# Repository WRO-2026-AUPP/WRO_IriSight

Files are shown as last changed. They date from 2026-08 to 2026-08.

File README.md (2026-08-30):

# IriSight — WRO Future Engineers 2026

_Repository of Team IriSight competing in the CRO 2026, Future Engineers category._

<div align="center">
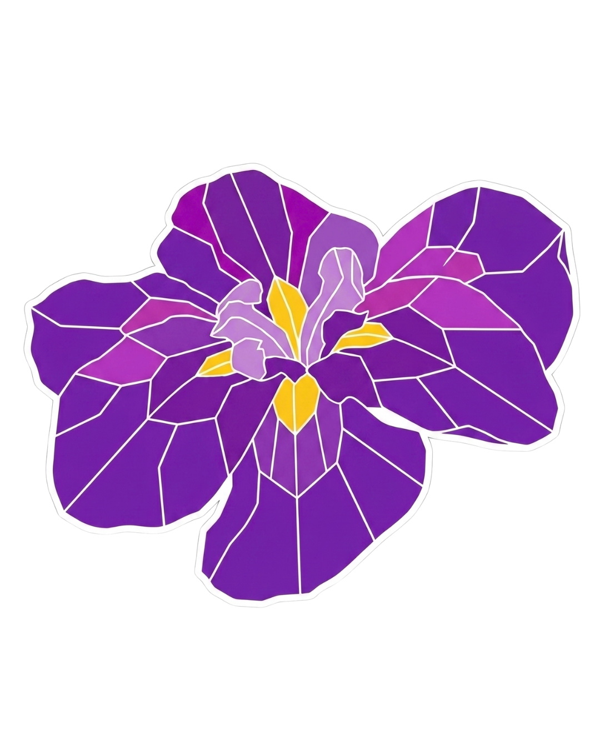
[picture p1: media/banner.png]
IriSight project banner
  
  <p><em>"Break, Fix, Repeat"</em></p>
</div>

## Quick Link - Explore the project

<table width="100%">
  <tr>
    <td width="33.33%" align="center" valign="top">
      <a href="src/"><strong>💻 Code</strong></a><br>
      <sub>Jetson and ESP32 control code</sub>
    </td>
    <td width="33.33%" align="center" valign="top">
      <a href="schemes/"><strong>🔌 Schematics</strong></a><br>
      <sub>Wiring, power, and electronics</sub>
    </td>
    <td width="33.33%" align="center" valign="top">
      <a href="models/"><strong>🧩 CAD models &amp; Mechanics</strong></a><br>
      <sub>Mechanical design and printable files</sub>
    </td>
  </tr>
  <tr>
    <td width="33.33%" align="center" valign="top">
      <a href="v-photos/"><strong>🚗 Vehicle Photos</strong></a><br>
      <sub>Required views of the final robot</sub>
    </td>
    <td width="33.33%" align="center" valign="top">
      <a href="t-photos/"><strong>👥 Team Photos</strong></a><br>
      <sub>Official and informal team photos</sub>
    </td>
    <td width="33.33%" align="center" valign="top">
      <a href="video/video.md"><strong>🎥 Videos</strong></a><br>
      <sub>Autonomous challenge demonstrations</sub>
    </td>
  </tr>
</table>

## Contents

- [Repository Structure](#repository-structure)
- [Meet the team](#meet-the-team)
- [Meet the vehicle](#meet-the-vehicle)
  - [Final vehicle gallery](#final-vehicle-gallery)
  - [Key specifications](#key-specifications)
- [Performance videos](#performance-videos)
- [How IriSight works](#how-irisight-works)
  - [System architecture](#system-architecture)
- [Our engineering journey](#our-engineering-journey)
  - [Final engineering blueprints](#final-engineering-blueprints)
- [Mobility and mechanical design](#mobility-and-mechanical-design)
  - [Chassis and component mounting](#chassis-and-component-mounting)
  - [Rear drive system](#rear-drive-system)
  - [Parallel steering](#parallel-steering)
  - [Mechanical iterations](#mechanical-iterations)
- [Power and sensor architecture](#power-and-sensor-architecture)
  - [Power architecture](#power-architecture)
  - [Component and interface map](#component-and-interface-map)
    - [Jetson](#jetson)
    - [Custom ESP32 Board](#custom-esp32-board)
    - [Motor Driver](#motor-driver)
    - [Steering Servo](#steering-servo)
    - [D455](#d455)
    - [IMU](#imu)
    - [Left/Right Ultrasonic](#leftright-ultrasonic)
    - [Jetson Battery](#jetson-battery)
    - [Motor Battery](#motor-battery)
    - [Buck-Boost Converter at 11V](#buck-boost-converter-at-11v)
    - [Buck Converter at 5V](#buck-converter-at-5v)
  - [Sensor placement and calibration](#sensor-placement-and-calibration)
- [Software and challenge strategy](#software-and-challenge-strategy)
  - [Architecture and communication](#architecture-and-communication)
  - [Open Challenge](#open-challenge)
    - [Current Control Value](#current-control-value)
    - [Test Results](#test-results)
  - [AI Model and Computer Vision Pipeline](#ai-model-and-computer-vision-pipeline)
    - [Detection Model](#detection-model)
    - [Dataset and Training Workflow](#dataset-and-training-workflow)
    - [How the Model Output Is Used in Control](#how-the-model-output-is-used-in-control)
  - [Obstacle Challenge](#obstacle-challenge)
    - [Current Control Values](#current-control-values)
    - [Test Results](#test-results-1)
- [System integration, testing, and risk](#system-integration-testing-and-risk)
  - [Subsystem interaction](#subsystem-interaction)
  - [Final regression results](#final-regression-results)
  - [Key decisions](#key-decisions)
  - [Risk register](#risk-register)
- [Reproducing IriSight](#reproducing-irisight)
  - [Required files and tools](#required-files-and-tools)
  - [Mechanical assembly](#mechanical-assembly)
  - [Wiring and power-on](#wiring-and-power-on)
  - [Software Installation](#software-installation)
  - [Calibration](#calibration)
  - [Start an Autonomous Run](#start-an-autonomous-run)
  - [Pre-flight and acceptance test](#pre-flight-and-acceptance-test)
- [Current limitations and next improvements](#current-limitations-and-next-improvements)
- [MIT License](#mit-license)

## Repository Structure

This repository is organized as follows:

```
📦 WRO_IriSight
├── 📁 media                    # Project banner and progress photos
│
├── 📁 models                   # 3D design files for the robot's printed components
│   ├── 📁 STEP_file             # Editable CAD source files
│   ├── 📁 STL_file              # Print-ready mesh files
│   └── 📁 png                   # Renders and engineering blueprints
│
├── 📁 schemes                  # Schematics and electrical documentation
│   ├── 📄 WRO_electrical_diagram.drawio  # Editable wiring/power diagram source
│   └── 📁 photos                # Photos and exported diagrams
│
├── 📁 src                      # Main source code for the robot
│   ├── 📁 ai_model              # YOLOv8n weights and object-detection docs
│   ├── 📁 helper_function       # BNO055 IMU driver, calibration data, ultrasonic firmware
│   ├── 📁 obs_challenge         # Obstacle Challenge control programs (CW/CCW)
│   └── 📁 open_challenge        # Open Challenge control programs (CW/CCW)
│
├── 📁 t-photos                 # Official and informal team photos
│
├── 📁 v-photos                 # Vehicle photo/video documentation
│   └── 📁 robot_photo           # Required six-side photos + 360° GIF
│
├── 📁 video                    # Link(s) to challenge demonstration videos
│
├── 📄 LICENSE.txt              # MIT License
└── 📄 README.md                # Main documentation for the project
```

## Meet the team

<div align="center">
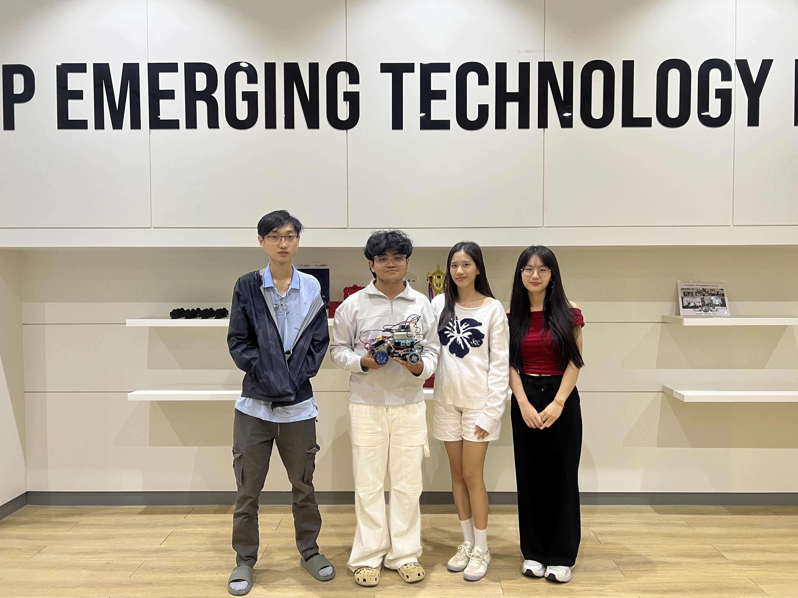
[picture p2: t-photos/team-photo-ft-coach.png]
Meet the team
  
  <p><em>Team Photo - From left to right: Kimchour, Panha (Coach), Nita, and Muyleang.</em></p>
</div>

<table style="border: 1px solid #ccc; width: 100%; border-collapse: collapse; margin-bottom: 20px;">
  <tr>
    <td width="30%" align="center" valign="top" style="padding: 15px; border-right: 1px solid #ccc;">
      <strong>Ponlork Ponita</strong><br><br>
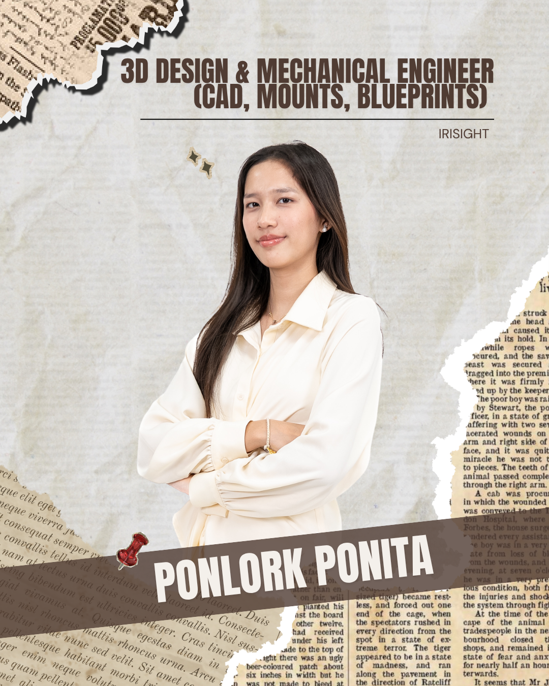
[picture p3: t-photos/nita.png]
Team member 1
      
    </td>
    <td width="70%" valign="top" style="padding: 15px;">
      <strong>Role:</strong> 3D Design & Mechanical Engineer (CAD, Mounts, Blueprints)<br><br>
      <strong>Origin:</strong> Phnom Penh<br><br>
      <strong>Email:</strong> 2024352ponlork@aupp.edu.kh<br><br>
      <strong>Bio:</strong> A junior student at the American University of Phnom Penh (AUPP), she led the CAD design of the team's 3D-printed structural parts. Including the Jetson & Battery Container, the rear Motor Mount, and the RealSense Camera Mount. She carried each component through multiple print-and-test-fit iterations to achieve a LEGO-compatible, chassis-mounted final version, meticulously documenting dimensions and material properties in her blueprint sheets.
    </td>
  </tr>
</table>

<table style="border: 1px solid #ccc; width: 100%; border-collapse: collapse; margin-bottom: 20px;">
  <tr>
    <td width="70%" valign="top" style="padding: 15px; border-right: 1px solid #ccc;">
      <strong>Role:</strong> Electrical & Sensor Engineer (Wiring, Power, Sensors)<br><br>
      <strong>Origin:</strong> Phnom Penh<br><br>
      <strong>Email:</strong> 2024355taing@aupp.edu.kh<br><br>
      <strong>Bio:</strong> Serving as the hardware integration lead, she managed the vehicle's electrical infrastructure. She mapped the custom wiring schematics, engineered a stable power distribution system for the compute and motor payloads, and rigorously tested and calibrated sensor placements to guarantee accurate real-time data collection for the system's navigation stack.
    </td>
    <td width="30%" align="center" valign="top" style="padding: 15px;">
      <strong>Taing Muyleang</strong><br><br>
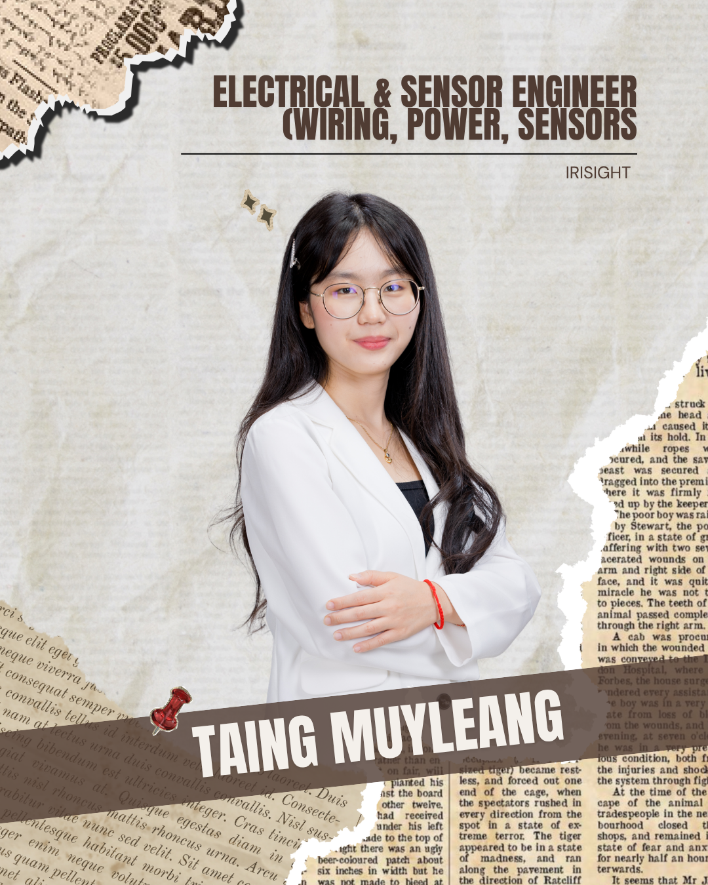
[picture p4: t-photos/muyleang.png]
Team member 2
      
    </td>
  </tr>
</table>

<table style="border: 1px solid #ccc; width: 100%; border-collapse: collapse; margin-bottom: 20px;">
  <tr>
    <td width="30%" align="center" valign="top" style="padding: 15px; border-right: 1px solid #ccc;">
      <strong>Luy Kimchour</strong><br><br>
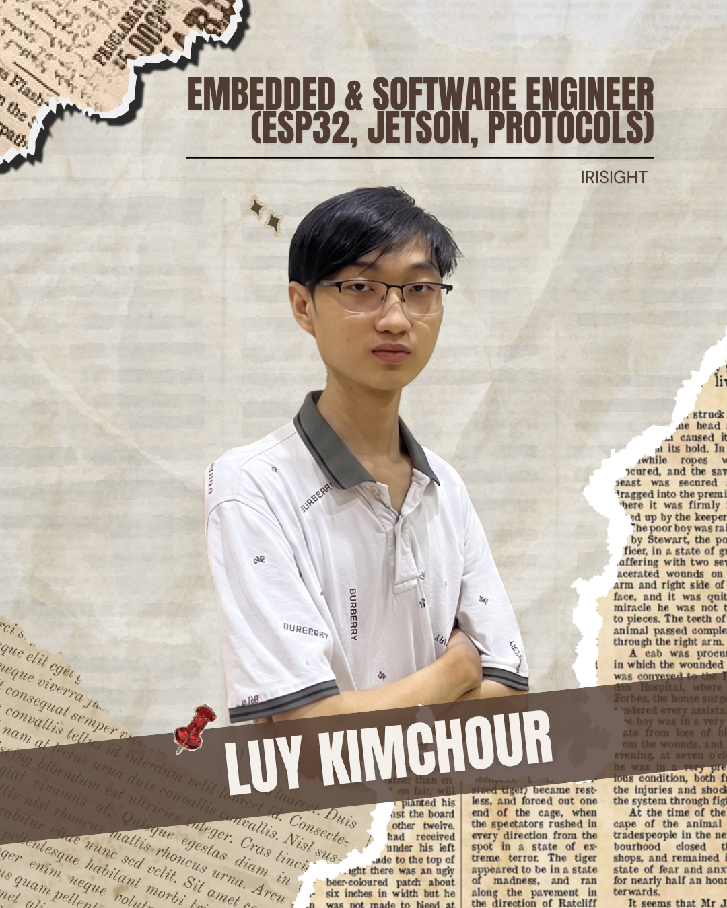
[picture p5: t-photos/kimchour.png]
Team member 3
      
    </td>
    <td width="70%" valign="top" style="padding: 15px;">
      <strong>Role:</strong> Embedded & Software Engineer (ESP32, Jetson, Protocols)<br><br>
      <strong>Origin:</strong> Phnom Penh<br><br>
      <strong>Email:</strong> 2025136luy@aupp.edu.kh<br><br>
      <strong>Bio:</strong> As the team's software lead, he developed the core system architecture, writing the ESP32 firmware and the Jetson control software. Backed by an extensive commit history in the project repository, his work focused on designing robust communication protocols to bridge the microcontrollers and compute modules, ensuring seamless data flow and reliable system execution.
    </td>
  </tr>
</table>

<table style="border: 1px solid #ccc; width: 100%; border-collapse: collapse; margin-bottom: 20px;">
  <tr>
    <td width="70%" valign="top" style="padding: 15px; border-right: 1px solid #ccc;">
      <strong>Role:</strong> Team Coach<br><br>
      <strong>Origin:</strong> Battambang<br><br>
      <strong>Email:</strong> 2024033chamroeun@aupp.edu.kh<br><br>
      <strong>Bio:</strong> A senior student majored in Information and Communication Technology at the American University of Phnom Penh, with experience in 3D modeling, CAD, vehicle design, and autonomous-vehicle software. In the previous season, he helped design and optimize the robot's custom parts and mechanical structure while also contributing to software, planning, coordination, and technical documentation. As IriSight's coach for the 2026 season, he uses that hands-on competition experience to guide the team through mechanical design, software development, system integration, testing, and documentation while keeping the engineering work student-led.
    </td>
    <td width="30%" align="center" valign="top" style="padding: 15px;">
      <strong>Chamroeun Vireakpanha</strong><br><br>
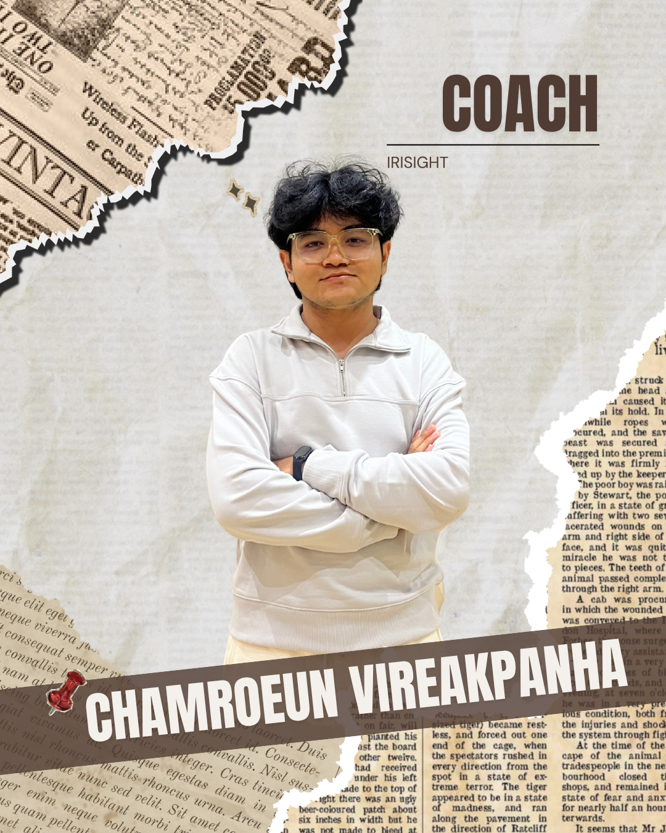
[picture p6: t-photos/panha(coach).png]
Team coach
      
    </td>
  </tr>
</table>

## Meet the vehicle
<div>
  Meet the vehicle
  <p><em>Vehicle 360º view (GIF)</em></p>
</div>

### Final vehicle gallery
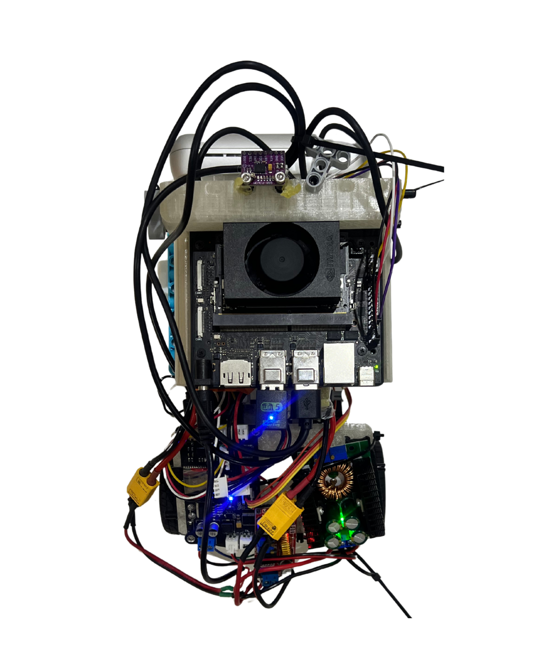
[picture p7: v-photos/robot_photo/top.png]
Top photo
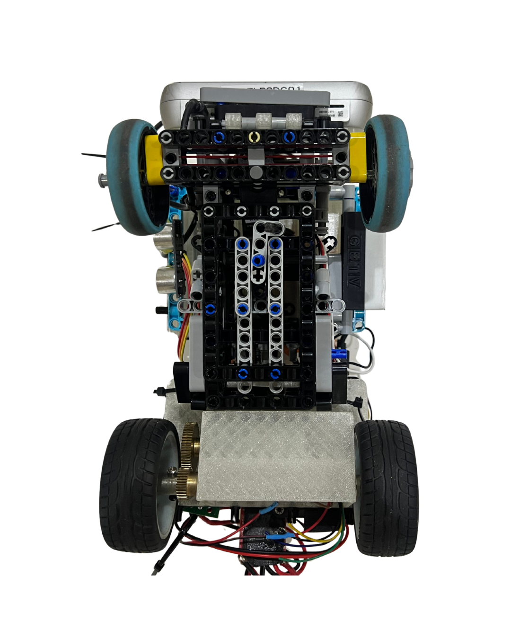
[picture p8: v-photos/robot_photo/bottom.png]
Bottom photo
|  |  |
| :---: | :---: |
| **Top** | **Bottom** |

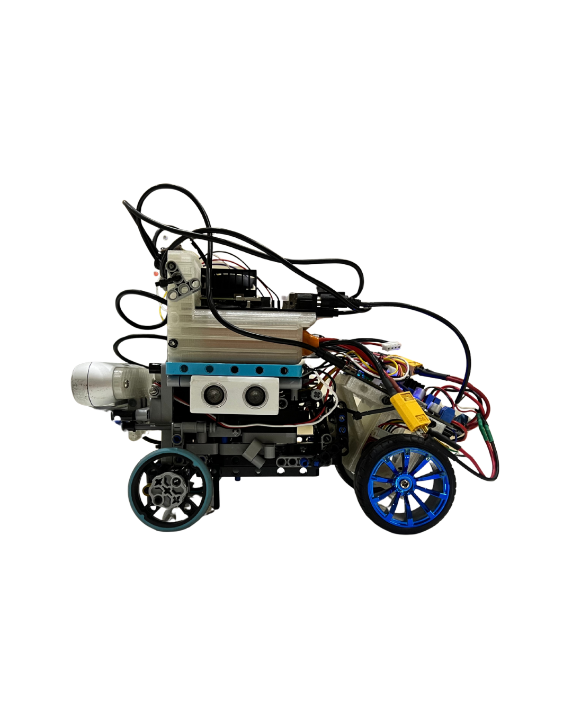
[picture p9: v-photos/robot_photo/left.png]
Left photo
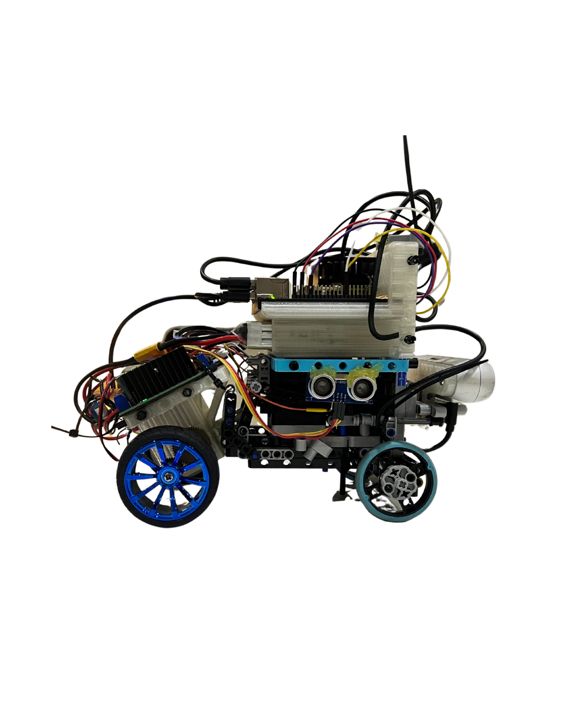
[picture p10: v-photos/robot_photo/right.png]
Right photo
|  |  |
| :---: | :---: |
| **Left** | **Right** |

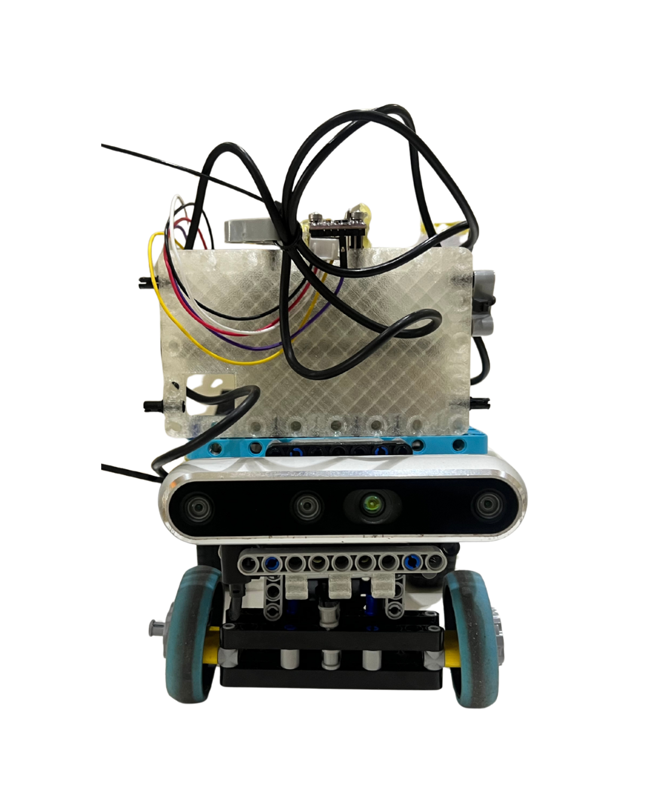
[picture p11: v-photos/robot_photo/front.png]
Front photo
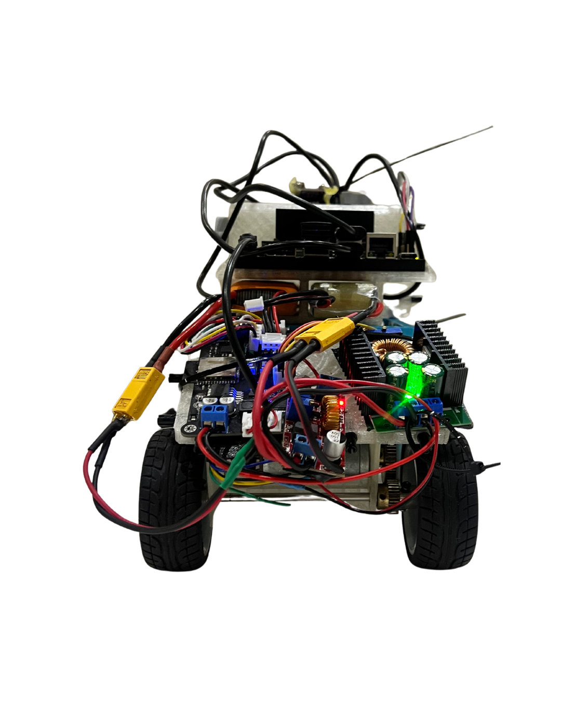
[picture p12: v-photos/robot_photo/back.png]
Back photo
|  |  |
| :---: | :---: |
| **Front** | **Back** |
### Key specifications

| Specification | Final value |
| --- | --- |
| Length × width × height | 26.3 x 15.2 x 21.2 (cm) |
| Mass | 1.38 KG |
| Wheelbase / track width | 15.3 cm |
| Ground clearance | 2.8 cm |
| Drive layout | One motor, two gears, one drive shaft, two driven back wheels |
| Steering layout | LEGO-based parallel front steering system|
| Main computer | NVIDIA Jetson Orin Nano, Ubuntu 22.04 LTS |
| Microcontroller | ESP32 |
| Primary camera | Intel RealSense D455 |
| IMU | BNO055 breakout |
| Additional sensors | Two side ultrasonic sensors |
| Chassis Type | Custom chassis |
| Front wheels | LEGO SPIKE blue wheels, part `39367` |
| Back wheels | RC Car Tires Wheels |
| Batteries | Separate Jetson and motor/actuator batteries |

## Performance videos

| Challenge | Video | 
| --- | --- |
| Open Challenge | [Watch on Youtube](https://youtu.be/7jsuhlpw6mA) | 
| Obstacle Challenge | [Watch on Youtube](https://youtu.be/TGH4JoCRx5o) | 

## How IriSight works

IriSight is a self-driving LEGO/3D-printed chassis robot built for WRO Future Engineers 2026. An NVIDIA Jetson Orin Nano runs the main perception and decision loop, reading depth/color from an Intel RealSense D455 and heading from a BNO055 IMU over I2C (plus two HC-SR04 ultrasonics wired to the ESP32 for close-range backup). The Jetson computes a steering angle and speed command and sends it over USB (power + serial) to an ESP32, which drives the rear motor through a TB6612FNG driver and turns the front wheels via a parallel-linkage steering servo. A Flask web stream exposes live diagnostics (mode, depth ROIs, steering, yaw, lap count) for tuning and debugging.

### System architecture

<div align="center">
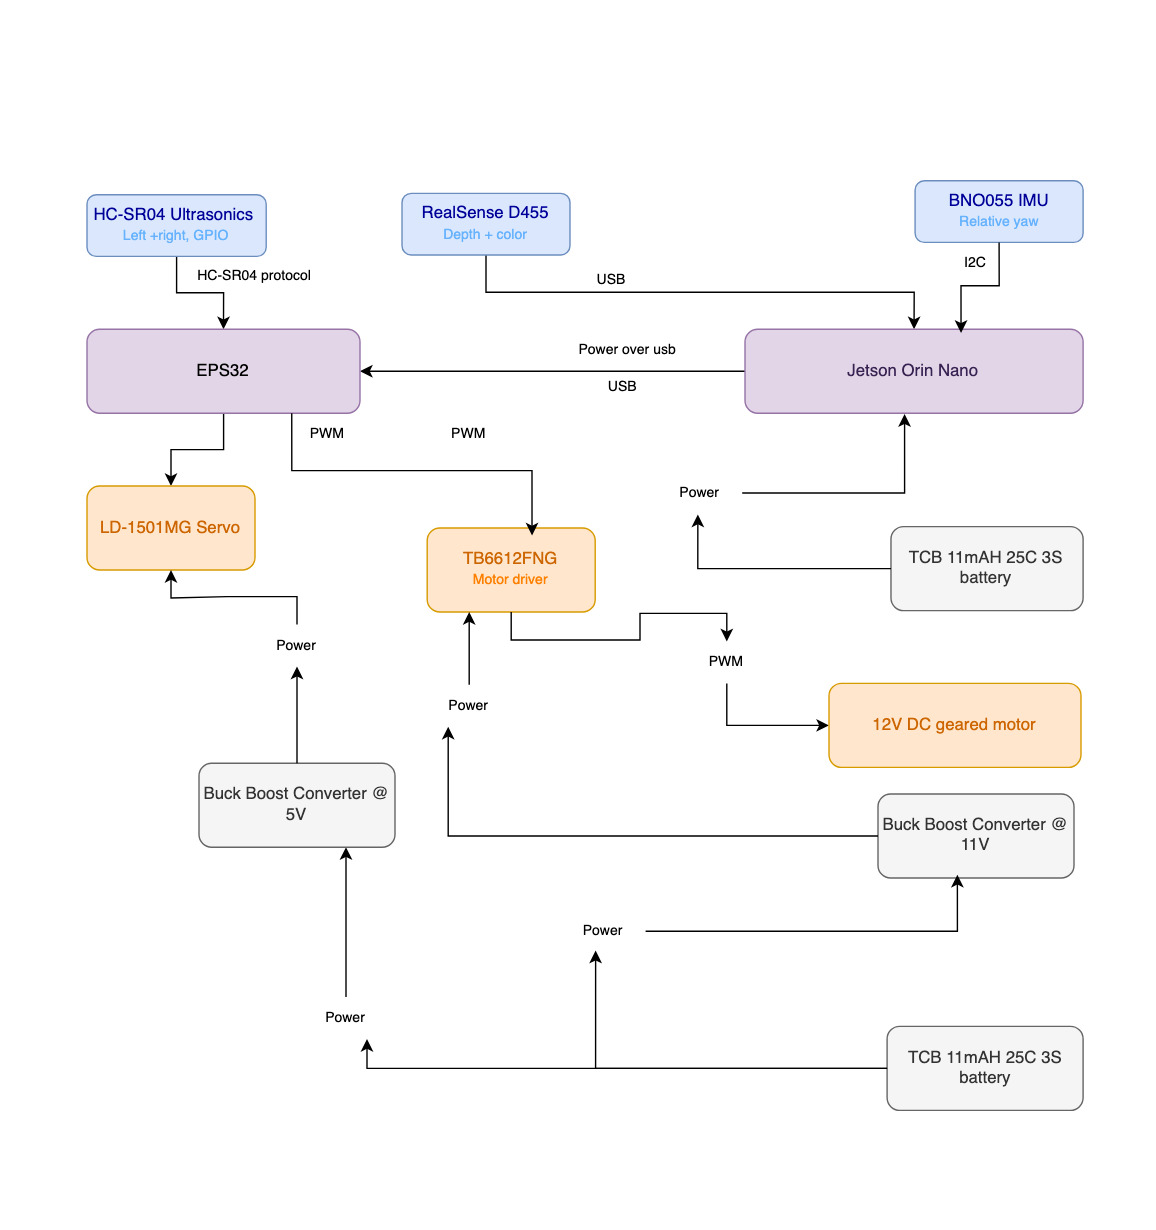
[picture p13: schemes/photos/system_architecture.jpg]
System architecture

</div>

| Flow | Summary |
| --- | --- |
| Power | Two isolated LiPo domains (TCB 1100mAh 3S each). One battery powers the Jetson directly. Its 9–20V DC input accepts raw 3S voltage with no regulation needed. The second battery splits into a 5V buck converter (servo power, TB6612 logic) and an 11V buck-boost converter (TB6612 motor supply), keeping motor-driver noise off the Jetson's rail. |
| Perception | RealSense D455 feeds 640×480 depth+color at 30 FPS to the Jetson over USB for wall distance, corner detection, and (planned) obstacle/pillar recognition via YOLOv8. BNO055 reports relative yaw to the Jetson over I2C for heading and lap-checkpoint tracking. Two HC-SR04 ultrasonics report to the ESP32 for side-facing close-range backup. |
| Decision | The Jetson runs a PD controller holding a 0.60 m side-wall target from depth ROIs, switches into a fixed-steering corner state using front-distance hysteresis (0.60 m entry / 0.80 m exit), and tracks laps via 90°±10° yaw checkpoints. Obstacle Challenge logic (YOLOv8-based) is in development. |
| Actuation | The Jetson sends DRIVE <steerDeg> <speed> over USB serial to the ESP32. The ESP32 converts this into PWM/enable signals for the TB6612FNG (driving the rear DC motor) and PWM for the LD-1501MG steering servo, limited to ±35°. |
| Feedback and safety | Depth readings outside 0.15–4.00 m or below a minimum valid-pixel count are rejected to avoid noisy control input. Corner-state hysteresis prevents mode flapping near threshold. A Flask diagnostic stream on port 5000 gives live visibility into control state for tuning and fault-spotting. |

## Our engineering journey

The mechanical layout was decided first: a LEGO-based chassis so geometry and mounting points could change without machining a new frame each time, driven by a DC motor at the rear and steered at the front. We attempted a LEGO Ackermann steering linkage, but couldn't get a working mechanism built in the available time, so parallel steering was selected for the current vehicle (see [Mobility and mechanical design](#mobility-and-mechanical-design)).

<div align="center">
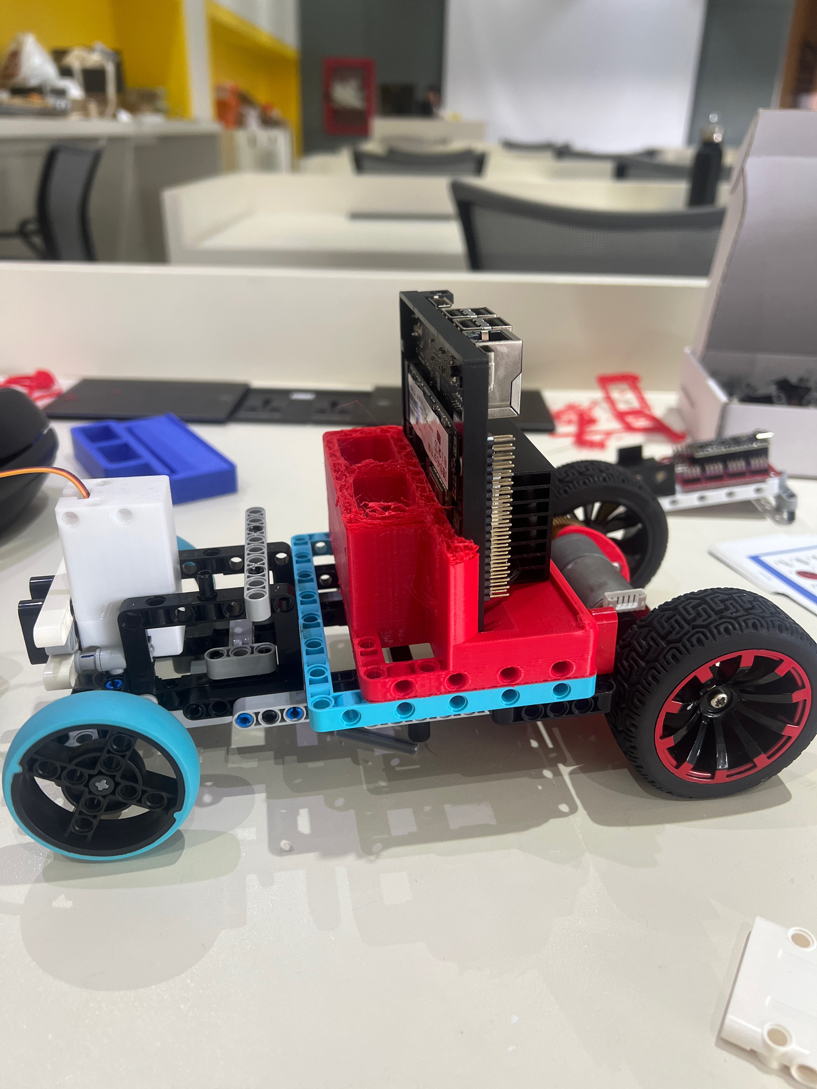
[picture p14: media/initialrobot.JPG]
First rolling prototype of IriSight
  
  <p><em>The very first rolling prototype — LEGO Technic chassis, steering servo, rear DC motor, and the rough-draft V1 Jetson &amp; battery container before it had any LEGO-native mounting.</em></p>
</div>

Once the chassis, steering, and drivetrain could be assembled and rolled by hand, the rest of the build became a sequence of small, testable 3D-printed parts rather than one big redesign. Each part went through its own print → test-fit → fix cycle, documented in full (renders, STL/STEP files, and final blueprints) in [`models/`](models/). The table below is the condensed version of that history:

| Version/date | Problem or goal | Change | Evidence | Result and next decision |
| --- | --- | --- | --- | --- |
| Concept | Steering mechanism | Attempted a LEGO Ackermann steering linkage | A working Ackermann mechanism could not be completed within the available build time | Parallel steering selected for the current vehicle |
| 2026-May-26 | Rear motor had no chassis mount | Designed Motor Mount V1 — a basic block cradle for the motor body, no LEGO connection yet | Established the core motor-holding shape | Chassis-attachment method still needed to be designed |
| 2026-May-27 | Jetson + battery had no housing | Designed Jetson & Battery Container V1, then printed a small test cut (P1) of it before committing to a full print | P1 came back with a small dimensional error against the real components | Adjust V1's compartment dimensions before the next full print (see photo above — V1 mounted on the first rolling prototype) |
| 2026-May-29 | Motor mount couldn't connect to the LEGO chassis | Redesigned to Motor Mount V2 with two LEGO Technic arms on a vertical axis, inspired by the LEGO Angle Beam | Printed and test-fit on the real robot: the vertical-axis arms misaligned with the front wheel/steering assembly and affected turning | Reorient the arms — a dimensional tweak alone would not fix a directional alignment problem |
| 2026-Jun-02 | Container had no LEGO-native mount | Redesigned to Jetson & Battery Container V2 with LEGO-pin-spaced holes, inspired by the LEGO Beam Frame | Container could now pin directly onto the chassis like any other LEGO part | Round over the exposed edges and add more mounting points |
| 2026-Jun-03 | Sharp edges and a mount that needed to be more rigid | Refined to Container V3: rounded corners/edges, extra LEGO-pin holes | Cleaner prints, more mounting points | Jetson & Battery Container finalized (V3) |
| 2026-Jun-05 | Camera needed a chassis mount | Designed RealSense Camera Mount V1: three LEGO pin arms, hole direction matching the camera's facing direction | Baseline design to compare against an alternative hole orientation | Print a second orientation and compare |
| 2026-Jun-09 | Compare mounting-hole orientations | Designed Camera Mount V2 with the pin holes rotated to face each other instead | Printed and tested both V1 and V2 on the robot: V2 mounted more easily and held more robustly | RealSense Camera Mount finalized (V2) |
| 2026-Jun-12 | Motor mount still misaligned with the front wheel | Reoriented Motor Mount V3's LEGO arms away from the vertical axis used in V2 | Fixed the front-wheel misalignment found with V2; arms also became easier to mount in general | Add a place to mount the rear electronics |
| 2026-Jun-14 | Rear electronics (ESP32, buck converter) had no mount | Finalized Motor Mount V4: reworked LEGO mounting plus a flat top plate as an electronics shelf | Motor cradle, LEGO mounting, and electronics shelf all fit together on one part | Motor Mount finalized (V4) and selected for the final robot |

### Final engineering blueprints

Each finalized 3D-printed part has a full blueprint sheet (orthographic views, dimensions, material, volume, and mass), generated from the final CAD model:

<div align="center">
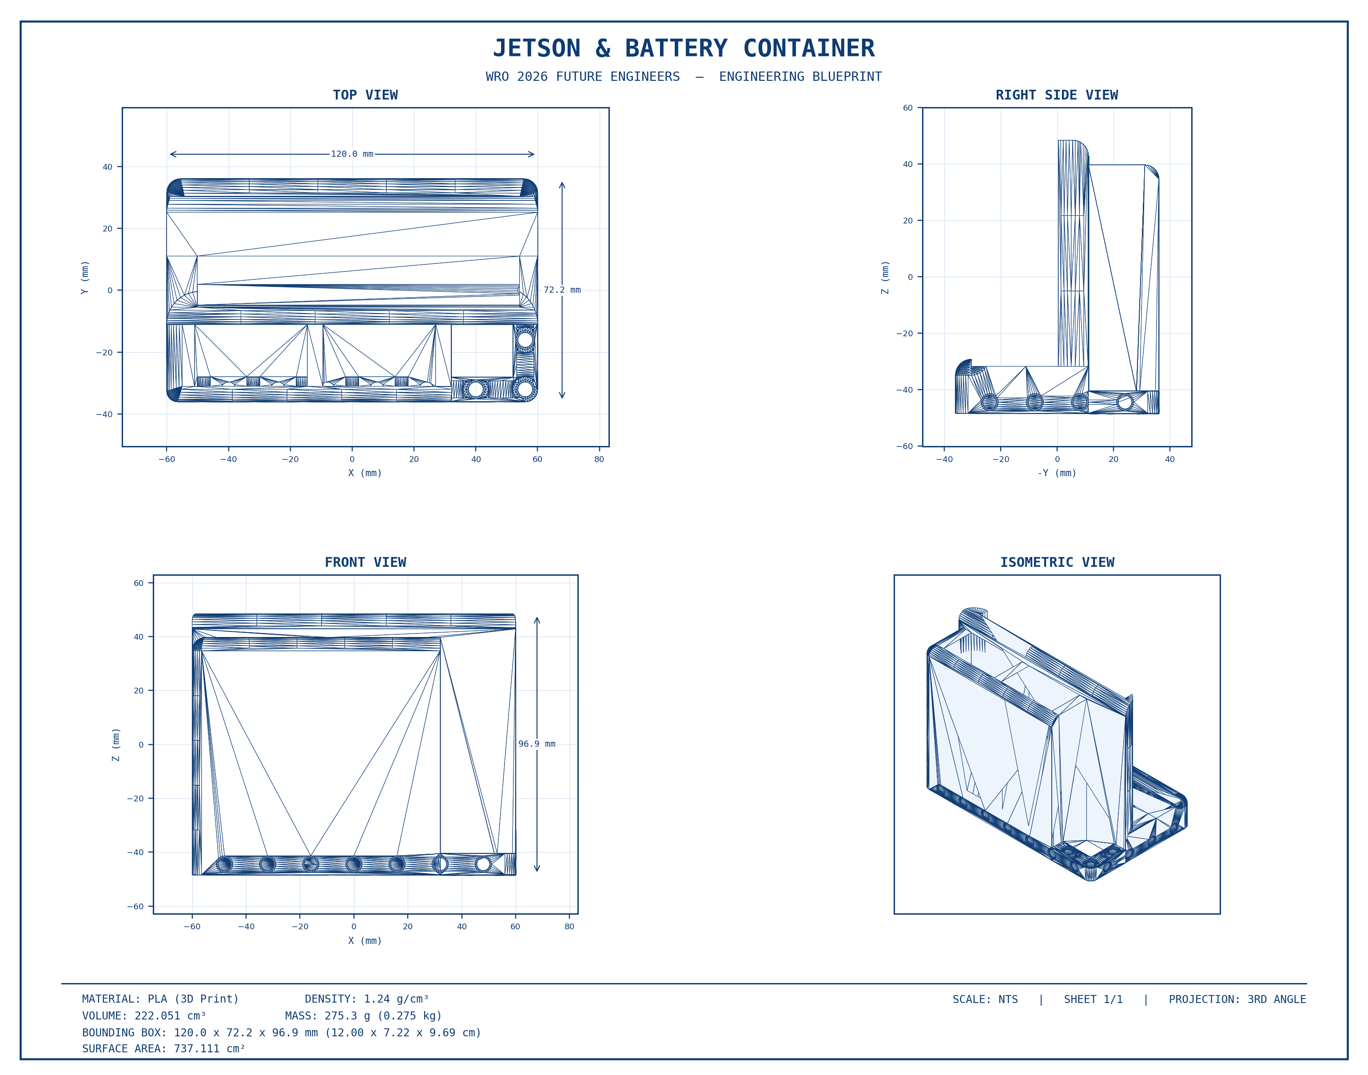
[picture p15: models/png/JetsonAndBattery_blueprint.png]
Jetson and Battery Container engineering blueprint
  
  <p><em>Jetson &amp; Battery Container — final blueprint (V3)</em></p>
</div>

<div align="center">
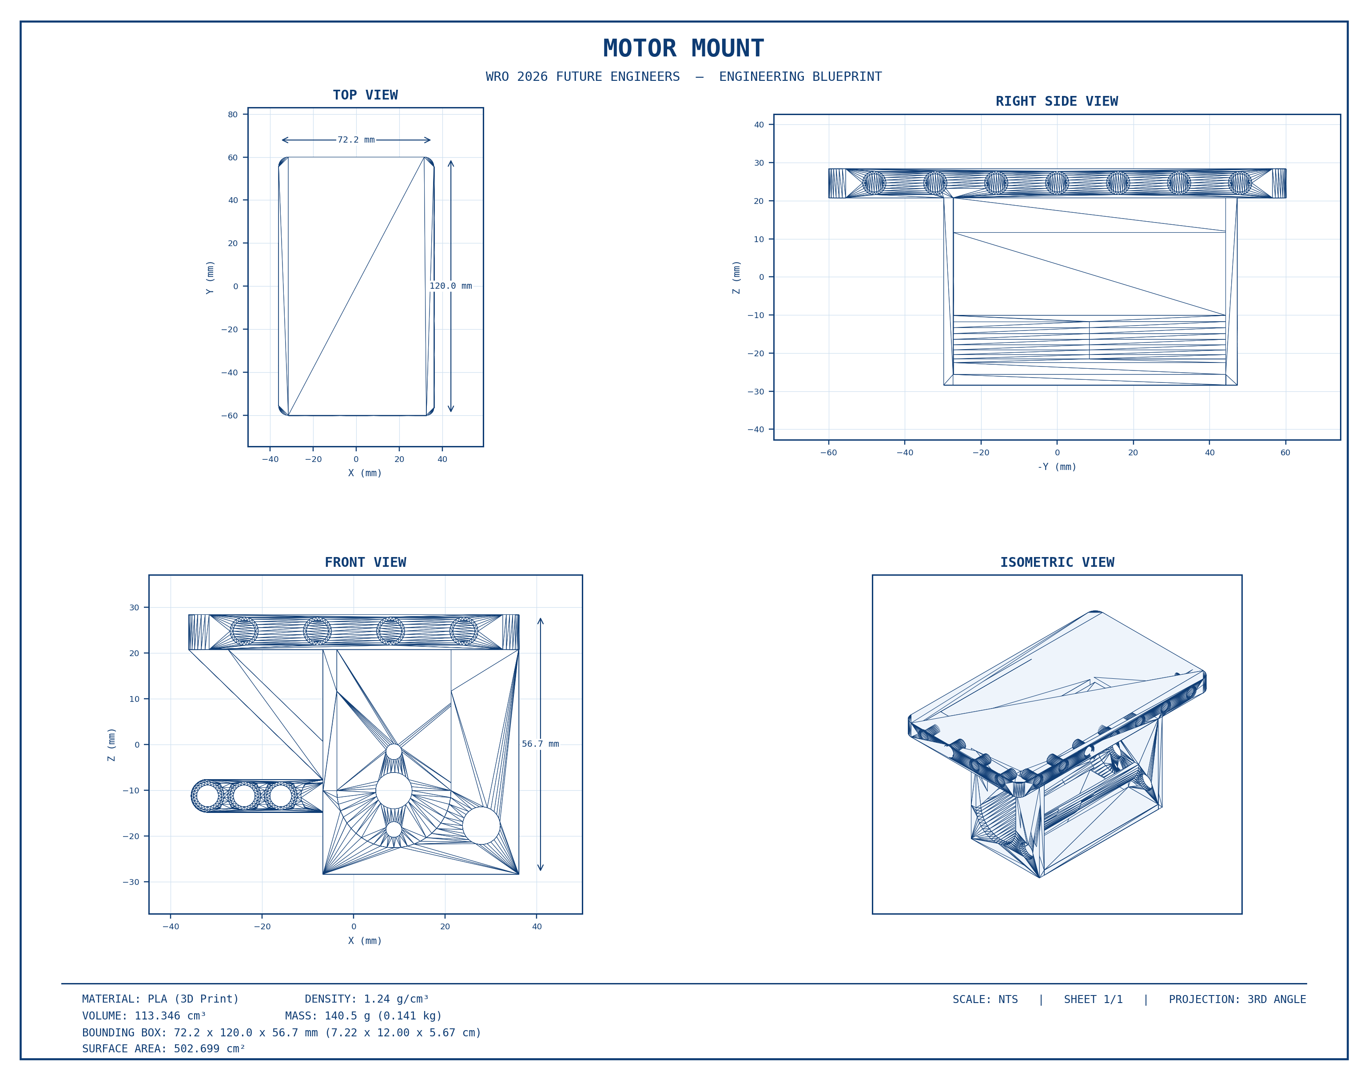
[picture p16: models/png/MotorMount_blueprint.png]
Motor Mount engineering blueprint
  
  <p><em>Rear Motor Mount — final blueprint (V4)</em></p>
</div>

<div align="center">
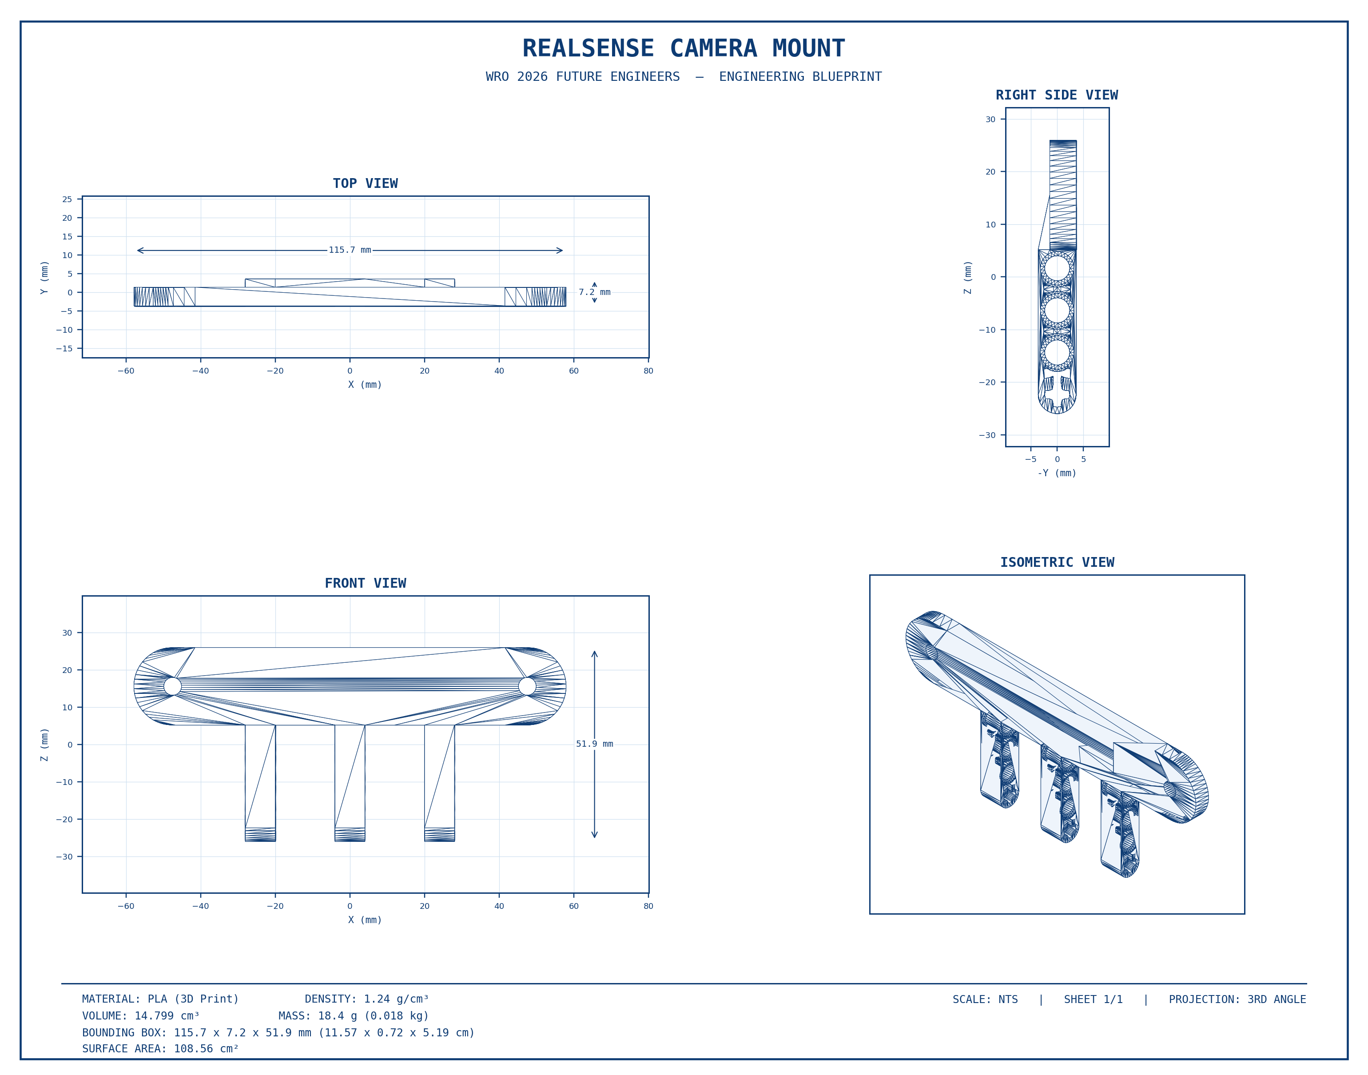
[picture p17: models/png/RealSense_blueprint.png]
RealSense Camera Mount engineering blueprint
  
  <p><em>RealSense Camera Mount — final blueprint (V2)</em></p>
</div>

**Full detail for every version above** — renders, STL/STEP files, and final engineering blueprints with dimensions and material properties — is in [`models/README.md`](models/README.md).

## Mobility and mechanical design

### Chassis and component mounting

IriSight uses a LEGO-based chassis so the team can change the geometry and component positions without manufacturing an entirely new frame. The Jetson is protected by a custom 3D-printed enclosure designed to connect directly to LEGO parts. The final dimensions, mass, mounting coordinates, rigidity checks, and center-of-mass measurements will be added after the mechanical configuration is frozen.

<!-- ### Torque and speed summary

| Result | Final value | Evidence |
| --- | ---: | --- |
| Gear ratio | [TODO] | [TODO] |
| Calculated no-load speed | [TODO] | [TODO] |
| Measured vehicle speed | [TODO] | [TODO] |
| Required wheel torque | [TODO] | [TODO] |
| Available wheel torque | [TODO] | [TODO] |
| Torque margin | [TODO] | [TODO] |
| Stopping distance | [TODO] | [TODO] | -->

### Rear drive system

One DC motor drives two rear wheels. Its output passes through a two-gear transmission to a drive shaft connecting the rear wheels. The motor and rear-wheel models are carried over from the previous vehicle, but their exact identifiers, gear tooth counts, ratio, mounting, and measured performance remain to be documented for the 2026 build.

### Parallel steering 

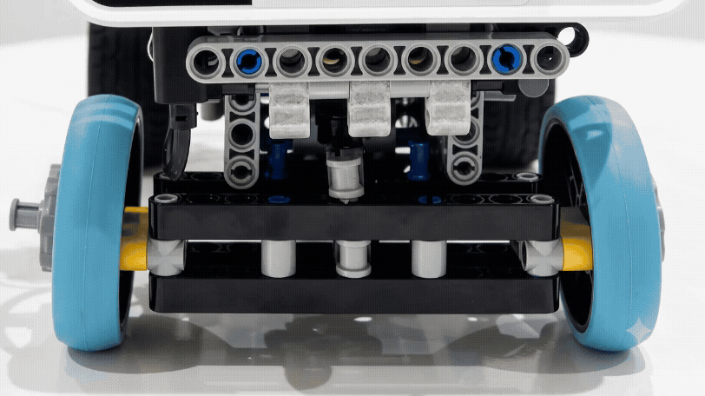
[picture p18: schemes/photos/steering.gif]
Parallel steering


The two front LEGO SPIKE `39367` wheels are steered by a larger servo through a LEGO parallel linkage. Ackermann steering was the original plan, but a suitable LEGO mechanism could not be completed within the available development time. The parallel mechanism was selected for the current vehicle; the final documentation will compare its geometry, steering play, turning radius, build complexity, and tire scrub with the attempted Ackermann design.

### Mechanical iterations

<table width="100%">
  <tr>
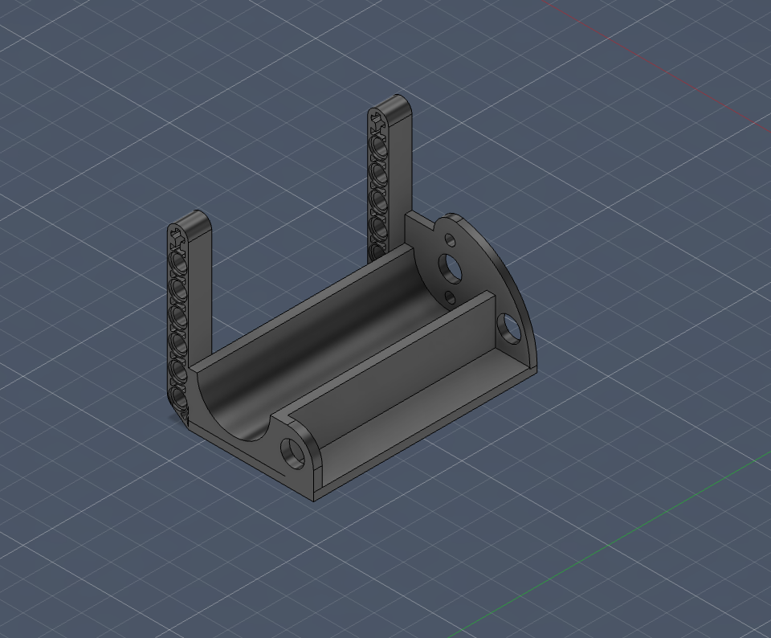
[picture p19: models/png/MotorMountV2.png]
    <td width="50%" align="center"><br><sub>Motor Mount V2 — vertical-axis LEGO arms (failed fit test)</sub></td>
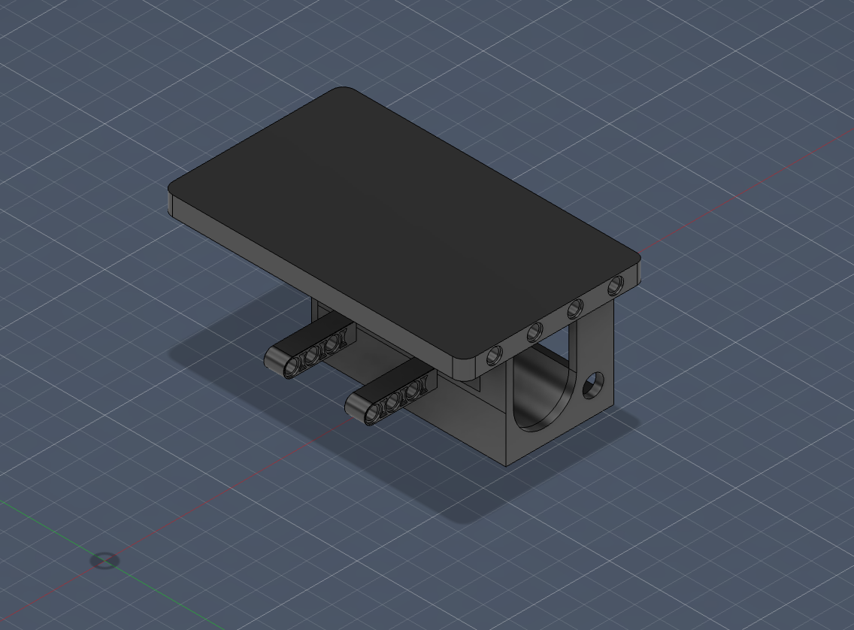
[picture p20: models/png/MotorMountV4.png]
    <td width="50%" align="center"><br><sub>Motor Mount V4 — reoriented arms + electronics shelf (final)</sub></td>
  </tr>
</table>

The full print → test-fit → fix history for every part is in the [Our engineering journey](#our-engineering-journey) table and in [`models/README.md`](models/README.md). The single largest lesson from that history came from the Motor Mount: V2's vertical-axis LEGO arms looked correct in CAD but, once test-fit on the real robot, misaligned with the front-wheel/steering assembly and affected turning. Reorienting the arms' axis in V3 (not just resizing them) is what actually fixed it — a reminder that a directional/alignment problem needs a geometry change, not a dimensional tweak. That is also why every structural part in this project is physically printed and test-fit on the robot before being called final, rather than approved from the CAD viewport alone.

**Detailed evidence:** [mechanical design, calculations, CAD, assembly, and validation](models/)

## Power and sensor architecture

### Power architecture

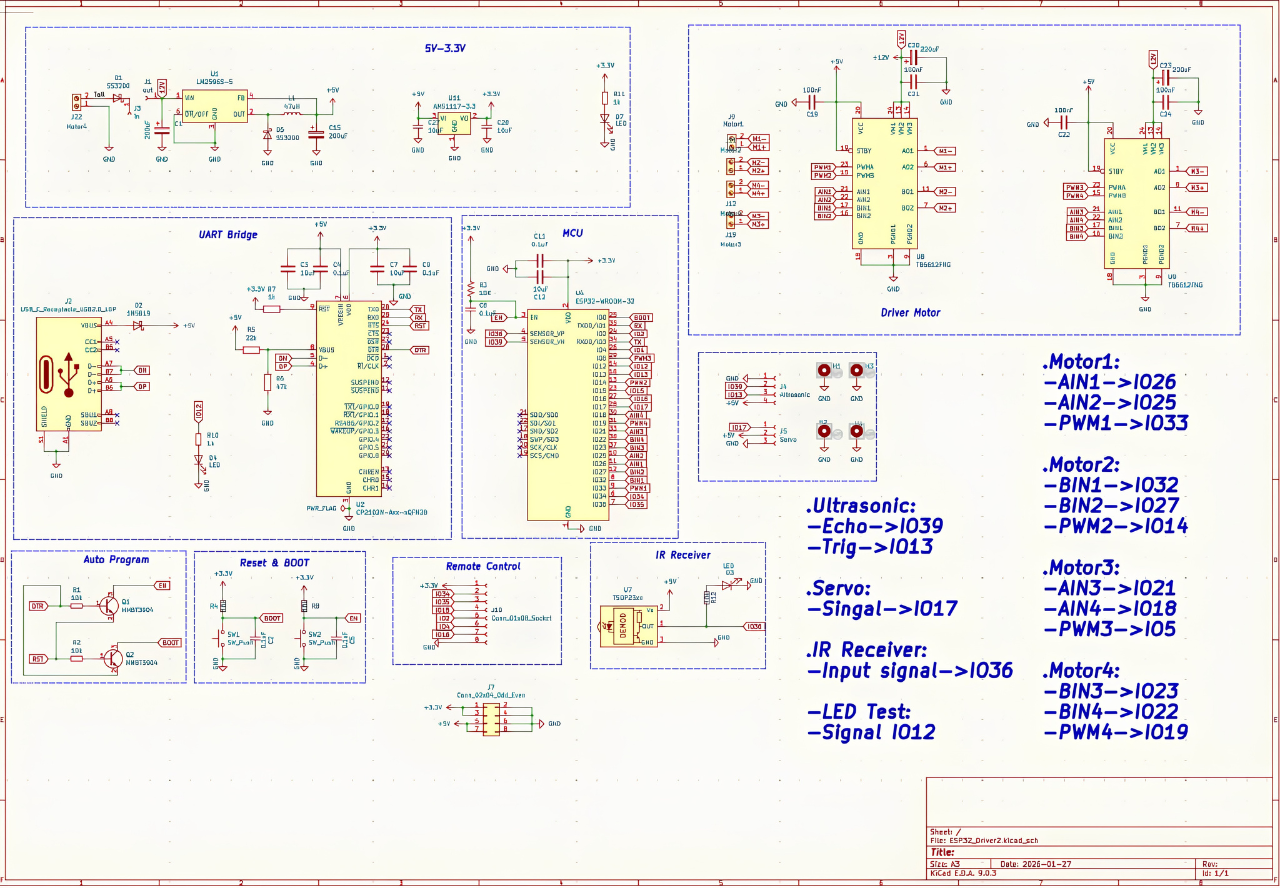
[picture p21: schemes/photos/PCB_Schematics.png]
Power architecture


The vehicle uses two battery domains: one battery supplies the Jetson and its logic/sensing system, while a second battery supplies the motor-driver side. A regulator provides the required stable voltage. Exact battery, regulator, motor-driver, connector, protection, and current ratings are still being identified and will be verified against measured typical and peak current.

| Power domain | Purpose | Voltage | Typical current |Power Consumption |
| --- | --- | ---: | ---: | --- |
| Jetson Orin Nano | Main Computing | 19V | 0.8A  | 15W | 
| Intel RealSense D4555 | Vision and depth-sensing | 5V | 0.4A | 2W |
| BMU BNO055 | Relative yaw | 3.3V | 0.02A | 0.2W |
| DC Motors | Driving the rear axle of the vehicle | 11.1V | 2.5A | 27.75W |
| LD-1501MG Servo | Control the steering mechanism | 6V | 0.3A | 1.85W |
| Miscellaneous | For miscalculation | 6V | 0.6A | 3W |

### Component and interface map
### Jetson

| Component  | Exact model  | Interface  | Purpose  | Details  |
| :--- | :--- | :--- | :--- | :--- |
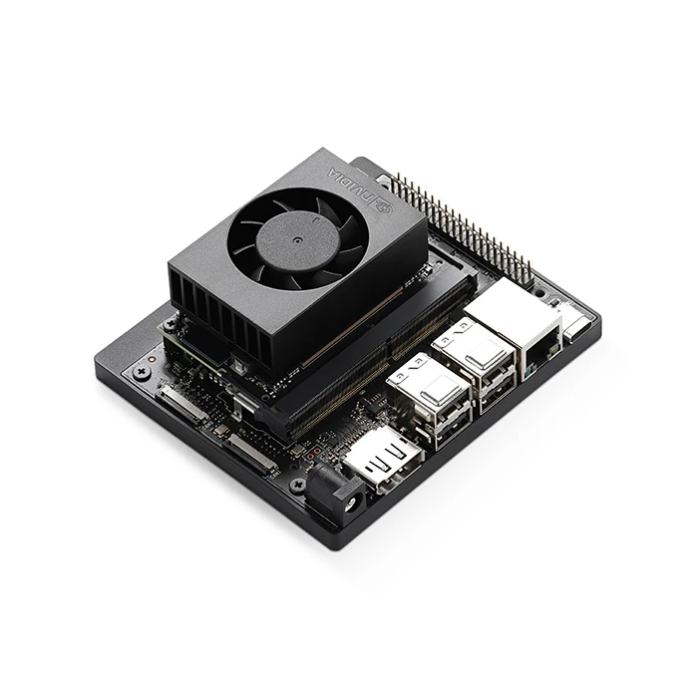
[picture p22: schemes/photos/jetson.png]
|  | NVIDIA Jetson Orin Nano | NaN | Main processing | [LINK](https://www.amazon.com/dp/B0BZJTQ5YP) |

### Custom ESP32 Board

| Component  | Exact model  | Interface  | Purpose  | Details  |
| :--- | :--- | :--- | :--- | :--- |
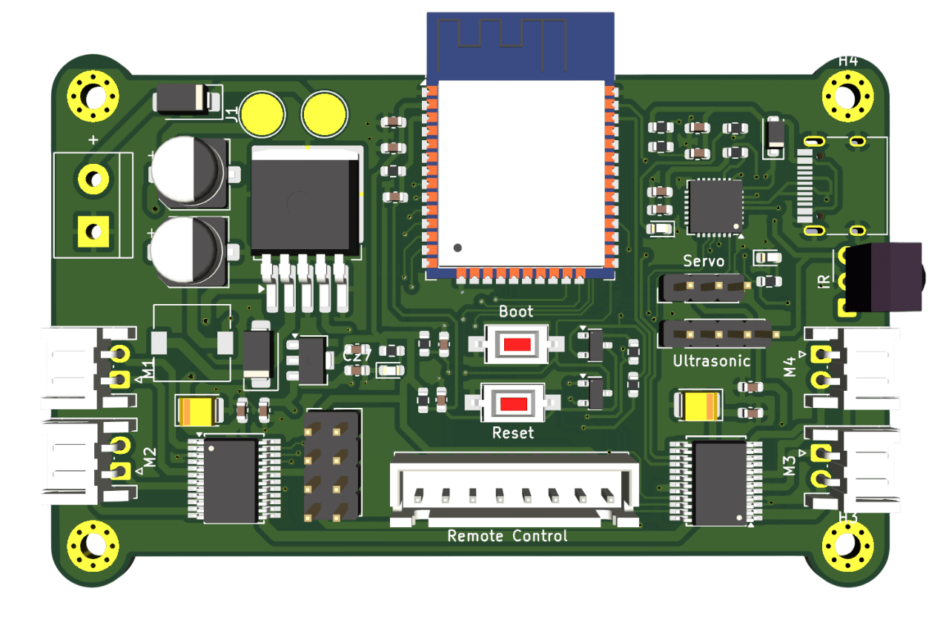
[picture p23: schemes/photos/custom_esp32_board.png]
|  | ESP32 WROOM Chip | Serial | Actuator control | [LINK](https://www.amazon.com/DORHEA-ESP-WROOM-32D-Bluetooth-integrates-ESP32-D0WD/dp/B08XXH9RMT?th=1) |

### Motor Driver

| Component  | Exact model  | Interface  | Purpose  | Details  |
| :--- | :--- | :--- | :--- | :--- |
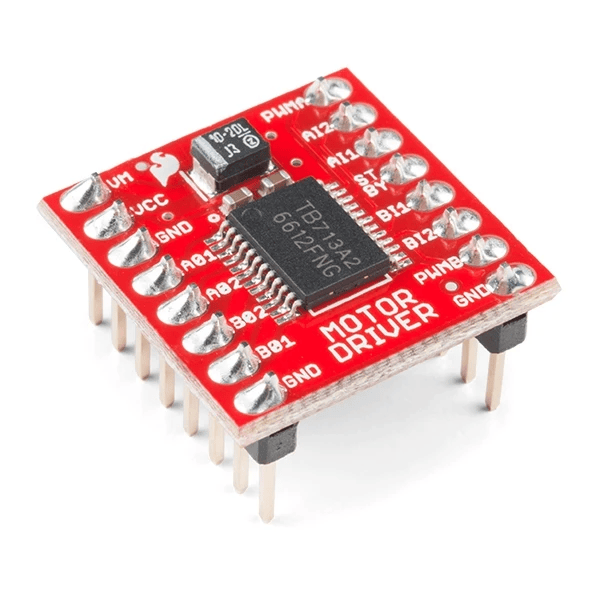
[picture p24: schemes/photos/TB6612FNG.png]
|  | TB6612FNG | PWM | Drive-motor control | [LINK](https://www.amazon.com/Sparkfun-PID-14451-Motor-Driver/dp/B01MF67DX6) |

### Steering Servo

| Component  | Exact model  | Interface  | Purpose  | Details  |
| :--- | :--- | :--- | :--- | :--- |
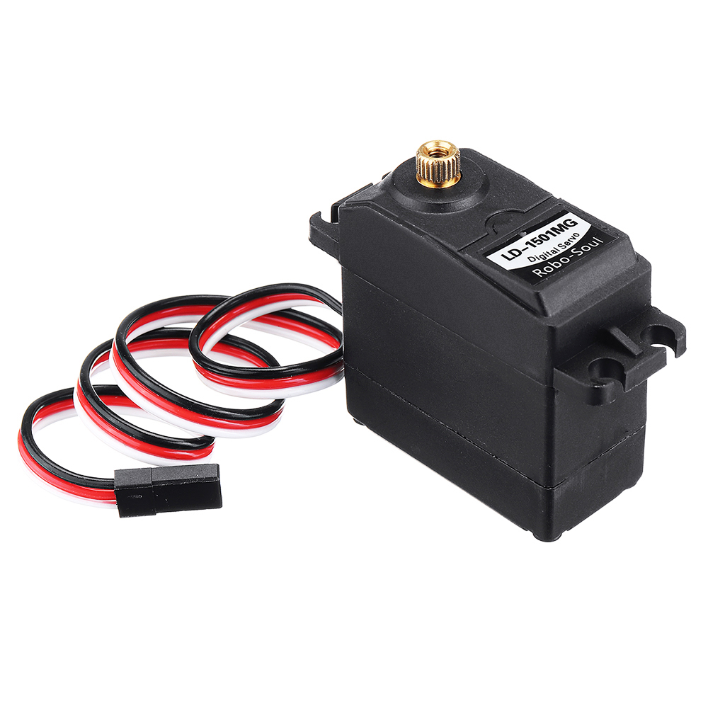
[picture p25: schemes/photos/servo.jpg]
|  | LD-1501MG Servo | PWM | Front steering | [LINK](https://www.ebay.com/itm/362680017196) |

### D455

| Component  | Exact model  | Interface  | Purpose  | Details  |
| :--- | :--- | :--- | :--- | :--- |
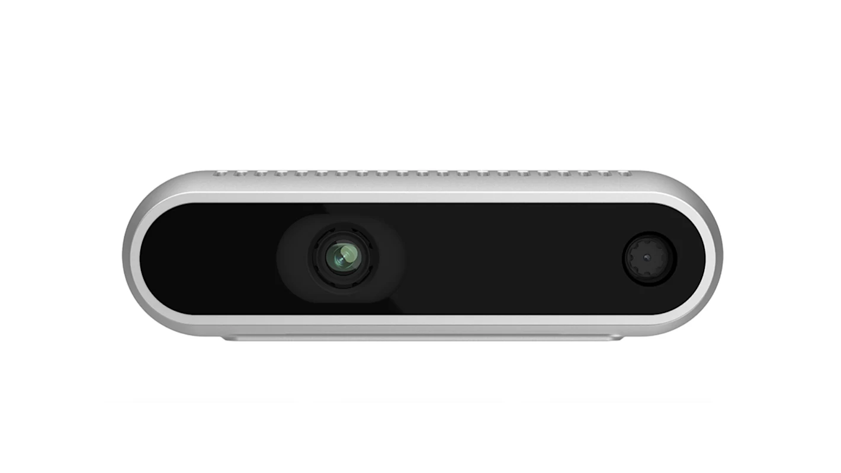
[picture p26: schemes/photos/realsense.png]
|  | Intel RealSense D455 | USB | Depth perception | [LINK](https://www.amazon.com/dp/B08KJCRCGG?) |

### IMU

| Component  | Exact model  | Interface  | Purpose  | Details  |
| :--- | :--- | :--- | :--- | :--- |
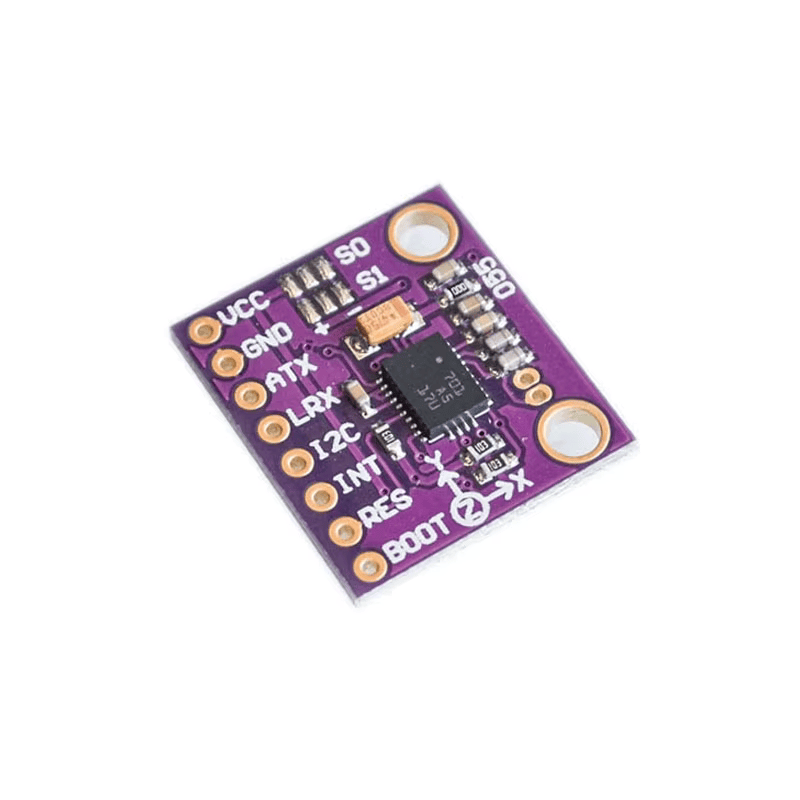
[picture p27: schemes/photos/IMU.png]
|  | BNO055 | I²C | Relative yaw | [LINK](https://bdelectronics.xyz/product/bno055-intelligent-9axis-attitude-sensor-module) |

### Left/Right Ultrasonic

| Component  | Exact model  | Interface  | Purpose  | Details  |
| :--- | :--- | :--- | :--- | :--- |
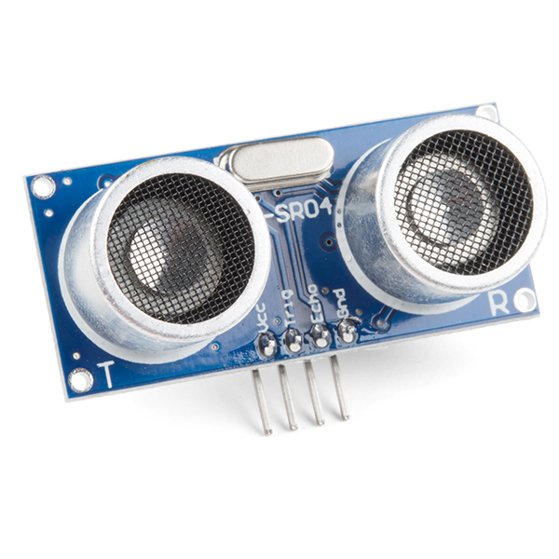
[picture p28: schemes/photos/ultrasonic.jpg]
|  | Generic HC-SR04 ultrasonic sensors | GPIO | Detect Wall | [LINK](https://www.amazon.com/MTDELE-HC-SR04-Ultrasonic-Mounting-Bracket/dp/B0G6ZDBTWR?) |

### Jetson Battery

| Component  | Exact model  | Interface  | Purpose  | Details  |
| :--- | :--- | :--- | :--- | :--- |
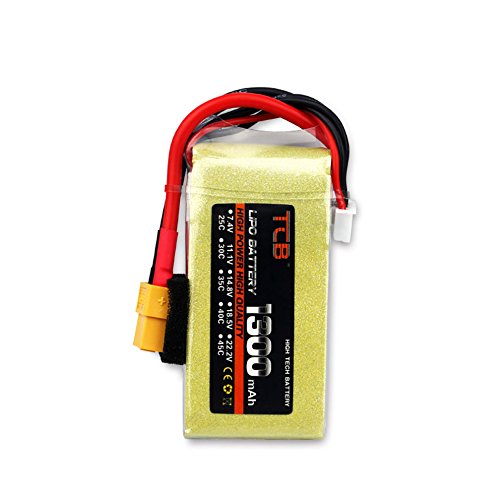
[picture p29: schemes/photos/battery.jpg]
|  | TCB 1100mAh 3S 25C battery | Power | Logic power | [LINK](https://rcdrone.top/products/tcb-2s-3s-4s-5s-6s-7s-8s-1100mah-25c-lipo-battery-with-xt60-plug-for-rc-planes-fpv-drones-helicopters-cars) |

### Motor Battery

| Component  | Exact model  | Interface  | Purpose  | Details  |
| :--- | :--- | :--- | :--- | :--- |
|  | TCB 1100mAh 3S 25C battery | Power | Actuator power | [LINK](https://rcdrone.top/products/tcb-2s-3s-4s-5s-6s-7s-8s-1100mah-25c-lipo-battery-with-xt60-plug-for-rc-planes-fpv-drones-helicopters-cars) |

### Buck-Boost Converter at 11V

| Component  | Exact model  | Interface  | Purpose  | Details  |
| :--- | :--- | :--- | :--- | :--- |
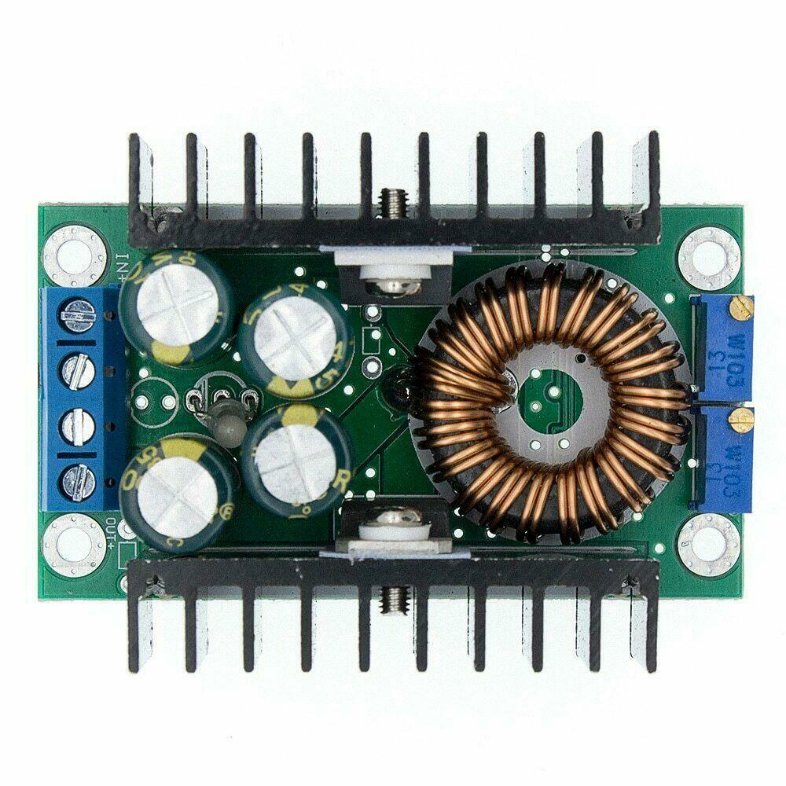
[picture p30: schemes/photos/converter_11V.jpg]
|  | XL4016 300W buck-boost converter | Power | Actuator power | [LINK](https://ampere-electronics.com/product/xl4016-dc-dc-step-down-converter-module-12a-300w/) |

### Buck Converter at 5V

| Component  | Exact model  | Interface  | Purpose  | Details  |
| :--- | :--- | :--- | :--- | :--- |
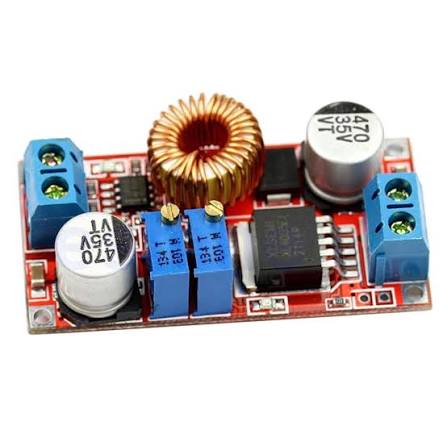
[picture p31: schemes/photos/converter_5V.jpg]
|  | XL4015 50W buck converter | Power | Actuator power | [LINK](https://www.jacobsparts.com/items/DCMOD-B) |

### Sensor placement and calibration

| Sensor | Placement | Selection reason | Calibration | Limitation and mitigation |
| --- | --- | --- | --- | --- |
| D455 | Mounted at the front/top of the robot, facing forward with a clear view of the track | Provides RGB and depth data for obstacle detection, pillar detection, wall following, and distance measurement | Mounted level and securely; depth readings are tested at known distances and filtered | Depth can be noisy on reflective, dark, or very close surfaces. ROI averaging/filtering and fallback control logic are used |
| BNO055 | Mounted on the upper section of the robot chassis, near the center and away from motors and power wiring as much as possible | Provides orientation and heading data for more stable navigation and turning | Calibrated according to the sensor's required motion/orientation procedure before operation | Magnetic interference and vibration can affect accuracy. The sensor is mounted securely, kept away from high-current components where possible, and readings are validated |
| Left ultrasonic | Mounted on the left side of the robot chassis, facing outward toward the left | Provides additional close-range obstacle and wall detection on the left side | Tested using objects at known distances; the detection threshold is adjusted based on test results | Can give inaccurate readings on angled, soft, or irregular surfaces. Used as an additional safety sensor with threshold-based filtering |
| Right ultrasonic | Mounted on the right side of the robot chassis, facing outward toward the right | Provides additional close-range obstacle and wall detection on the right side | Tested using objects at known distances; the detection threshold is adjusted based on test results | Can give inaccurate readings on angled, soft, or irregular surfaces. Used as an additional safety sensor with threshold-based filtering |

**Detailed evidence:** [electrical architecture, wiring, power budget, sensor placement, calibration, and safety](schemes/)

## Software and challenge strategy

### Architecture and communication

The current Open Challenge system runs on the Jetson. It reads the RealSense D455 and BNO055, calculates steering and speed, and sends `DRIVE <steerDeg> <speed>` commands to the ESP32 through a 115200-baud serial connection. The ESP32-side firmware that converts these commands into motor-driver and steering-servo signals still needs to be added to the repository.

| **Module** | **Responsibility** | **Inputs** | **Outputs** |
|---|---|---|---|
| [`src/clockWise.py`](https://github.com/WRO-2026-AUPP/WRO_IriSight/blob/main/src/clockWise.py) | Left-wall depth following with counter-clockwise yaw checkpoints | D455 depth/color, BNO055 yaw | ESP32 drive command, web diagnostics |
| [`src/counterClockWise.py`](https://github.com/WRO-2026-AUPP/WRO_IriSight/blob/main/src/counterClockWise.py) | Right-wall depth following with clockwise yaw checkpoints | D455 depth/color, BNO055 yaw | ESP32 drive command, web diagnostics |
| `src/bno055_yaw.py` | BNO055 yaw reading, calibration, and relative-heading tracking | BNO055, `bno055_calibration.json` | Relative yaw and calibration status |
| `bno055_calibration.json` | Stores the saved BNO055 calibration offsets used to restore sensor calibration | Saved calibration values | Calibration data for `bno055_yaw.py` |
| ESP32 firmware | Receives Jetson drive commands and controls the motors and steering servo | Jetson serial command | Motor-driver and servo control |

### Open Challenge

**Status:** Implemented for both directions.

Both programs align 640×480 depth and color frames at 30 FPS. They calculate the median of valid depth pixels inside front and side regions of interest, rejecting depths outside 0.15–4.00 m and requiring at least 50 valid pixels. On a straight, a PD controller maintains a 0.60 m side-wall target. If the side wall becomes unavailable, the program applies a small search steering command toward the missing wall.

When the median front distance reaches 0.60 m, the controller enters a fixed-steering corner state. It remains in that state until the front opens to 0.80 m, providing hysteresis so noise near one threshold does not repeatedly switch modes. Straight and corner speed commands are currently 200 and 180 on the program's 0–255 command scale. Steering is limited to ±35 degrees.

The BNO055 heading is zeroed at startup. Each program accepts the next expected 90-degree checkpoint within a ±10-degree zone, counts a lap only after all four checkpoints arrive in order, and stops after three laps plus a 0.5-second delay. A Flask diagnostic stream on port 5000 overlays the active mode, depth regions, steering, speed, yaw, lap count, and next checkpoint.

#### Current Control Value

| **Control value** | **Value** |
| --- | ---: |
| Side-wall target | 0.60 m |
| Front corner entry | 0.60 m |
| Front corner exit | 0.80 m |
| Proportional gain | 38.0 steering degrees/m |
| Derivative gain | 4.0 |
| Steering limit | ±35° |
| Straight/corner speed command | 200 / 180 |
| D455 stream | 640×480 at 30 FPS |
| Yaw checkpoint tolerance | ±10° |
| Required laps | 3 |

#### Test Results

| **Metric** | **Clockwise** | **Counter-clockwise** | 
| --- | ---: | ---: |
| Trials | 30 | 30 | 
| Successful three-lap runs | 28/30| 27/30| 
| Success rate | 93.33% | 90%|
| Best/average completion time | 44s| 44s| 

### AI Model and Computer Vision Pipeline

IriSight's perception stack combines depth-based geometric sensing with a trained computer vision pipeline running on the **Jetson Orin Nano**. The **Intel RealSense D455** provides aligned depth and color frames at **640 × 480 resolution and 30 FPS**.

The perception system uses two complementary approaches:

- **Depth processing** for wall following and distance measurement
- **YOLOv8n object detection** for pillar and parking-lot recognition

#### Detection Model

- **Model:** YOLOv8n (nano) — chosen for its speed/accuracy tradeoff, allowing it to run in real time on the Jetson alongside the depth-processing pipeline.
- **Classes:** `greenbox`, `redbox`, `xparking`
- **Input size:** 640 × 640
- **Inference:** Runs on the Jetson Orin Nano using `ultralytics`, consuming the RealSense D455 color stream.
- **Depth integration:** YOLO bounding boxes are combined with the aligned depth frame to estimate the real-world distance and lateral offset to each detected object, rather than relying only on its position in the 2D image.
- **Training run:** 100 epochs, batch size 8, auto optimizer, `lr0 = 0.01`.
- **Validation performance:** Precision ≈ 0.997, recall ≈ 0.985, mAP@50 ≈ 0.995, mAP@50–95 ≈ 0.928.
- **Weights file:** `best1.pt` — the best checkpoint by validation fitness, used directly for inference on the robot.

<div align="center">
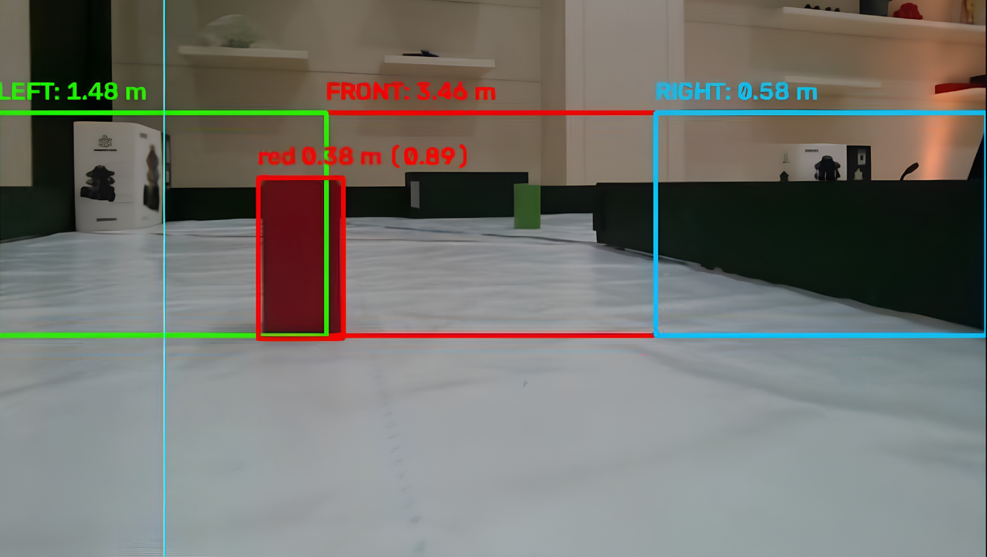
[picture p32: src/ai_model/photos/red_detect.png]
red pillar
  
  <p><em>Live detection output — bounding boxes and confidence scores for <code>redbox</code> on the RealSense color stream.</em></p>
</div>

### AI Model and Computer Vision Pipeline

IriSight's perception stack combines depth-based geometric sensing with a trained computer vision pipeline running on the **Jetson Orin Nano**. The **Intel RealSense D455** provides aligned depth and color frames at **640 × 480 resolution and 30 FPS**.

The perception system uses two complementary approaches:

- **Depth processing** for wall following and distance measurement
- **YOLOv8n object detection** for pillar and parking-lot recognition

#### Detection Model

- **Model:** YOLOv8n (nano) — chosen for its speed/accuracy tradeoff, allowing it to run in real time on the Jetson alongside the depth-processing pipeline.
- **Classes:** `greenbox`, `redbox`, `xparking`
- **Input size:** 640 × 640
- **Inference:** Runs on the Jetson Orin Nano using `ultralytics`, consuming the RealSense D455 color stream.
- **Depth integration:** YOLO bounding boxes are combined with the aligned depth frame to estimate the real-world distance and lateral offset to each detected object, rather than relying only on its position in the 2D image.
- **Training run:** 100 epochs, batch size 8, auto optimizer, `lr0 = 0.01`.
- **Validation performance:** Precision ≈ 0.997, recall ≈ 0.985, mAP@50 ≈ 0.995, mAP@50–95 ≈ 0.928.
- **Weights file:** `best1.pt` — the best checkpoint by validation fitness, used directly for inference on the robot.

#### Dataset and Training Workflow

The training dataset was developed using a **semi-supervised annotation workflow**. The full labeled dataset is browsable on [Roboflow](https://app.roboflow.com/join/eyJhbGciOiJIUzI1NiIsInR5cCI6IkpXVCJ9.eyJ3b3Jrc3BhY2VJZCI6ImFaSVNnTTJTbE1jSkVhcUlBbzFTbHdnRERyTzIiLCJyb2xlIjoib3duZXIiLCJpbnZpdGVyIjoiY2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).

1. **Manual annotation** — Approximately 300 images were manually annotated using **CVAT** to create the initial training set.
2. **Pseudo-labeling** — The trained model was used to automatically generate labels for additional unlabeled images.
3. **Manual correction** — The predicted labels were reviewed and corrected in CVAT.
4. **Dataset expansion** — The corrected annotations were added back into the training dataset, and the process was repeated to improve the model without manually annotating every frame from scratch.

Supporting scripts are used to:

- Organize images and labels
- Split the dataset into training and validation sets
- Test trained model checkpoints
- Run inference using a webcam
- Run inference directly on the Jetson Orin Nano

This workflow allows new model checkpoints to be validated before deployment into the competition control programs.

> **Note:** [`src/ai_model/README.md`](src/ai_model/README.md) documents the model checkpoint itself (`conf=0.5`, `imgsz=640`) for standalone testing (e.g. `yolo detect predict`). The live Obstacle Challenge scripts (`obs_clockwise.py` / `obs_counterclockwise.py`) load the same `best1.pt` weights but call it with the tuned in-competition settings listed under [Current Control Values](#current-control-values) — `imgsz=416` and a colour-dependent `conf` range of 0.35–0.70 — for faster, more responsive inference on the Jetson during a run.

#### How the Model Output Is Used in Control

The vision model does **not directly control the robot**. Instead, its output is passed to the existing **PD wall-following and checkpoint state machine**.

The main uses of the model output are:

- **Pillar distance:** The depth distance to a detected pillar determines when the robot should begin avoidance and how aggressively it should react.
- **Obstacle avoidance:** Separate control gains for green and red pillars allow the robot to apply different steering responses depending on the detected obstacle. Green pillars are passed on one side, while red pillars are passed on the other.
- **Error clamping:** Steering errors are constrained to prevent excessive corrections and reduce oversteering.
- **Parking maneuver:** Once `xparking` is detected and the required laps are complete, detections of this class are used to align the robot with the parking space and trigger the final parking sequence.
- **Ultrasonic backup:** Ultrasonic sensors provide redundant close-range confirmation so a missed or late detection does not immediately result in a collision.

The system therefore separates **perception** from **control**:

```text
RealSense D455
      │
      ├── Color Frame ──► YOLOv8n
      │                     │
      │                     ├── Object Class
      │                     └── Bounding Box
      │
      └── Depth Frame ───────┐
                             │
                             ▼
                    Object Distance
                             │
                             ▼
                  PD / State Machine
                             │
                             ▼
                     Steering + Speed
                             │
                             ▼
                           ESP32
```
### Obstacle Challenge

**Status:** Implemented for both directions.

Both programs run a YOLO detector (`best1.pt`) on the color frame to detect red and green pillars. Detection uses a confidence threshold of **0.35–0.70** and an inference size of **416 px**.

Detected bounding boxes are masked out of the depth image before the front and side wall ROIs are calculated. This prevents a pillar from being mistaken for the wall behind it. Each pillar's distance is calculated using the median depth from the center region of its bounding box.

Once a pillar is closer than its configured **engage distance**, the program begins tracking it and calculates steering from the pillar's horizontal position relative to a target column. The target position changes depending on the pillar colour and which third of the frame contains the pillar. Green-pillar targets steer the robot left past the pillar, while red-pillar targets steer it right. The steering correction is scaled using a proportional gain.

If a pillar is detected while the robot is performing a corner turn, the corner turn is cancelled and pillar avoidance takes priority for a short **lock window**. This prevents the controller from rapidly switching between corner-turning and pillar avoidance.

Independent wall-clearance guards are applied after the pillar-avoidance steering is calculated. These guards can reduce or override the avoidance steering as the relevant side-wall distance becomes too small. Ultrasonic sensors provide a second clearance check.

The robot also reduces its speed while actively avoiding a pillar. The more cautious program can additionally perform a slow stop-and-reverse maneuver if the front wall or pillar becomes dangerously close before the pass is complete.

#### Current Control Values

| **Control Value** | **Current Value** |
| --- | --- |
| Detector | `best1.pt`, `imgsz=416`, confidence 0.35–0.70 |
| Pillar engage distance | 1.6–2.2 m, colour-dependent |
| Pillar pass distance | 0.25–0.70 m |
| Steering gain (pillar column error) | 35–100 deg/unit, colour-dependent |
| Target column (front zone) | Green: ~0.75–0.80 / Red: ~0.08–0.42 |
| Avoid speed command | 110–160 |
| Corner-lock window on pillar-during-turn | 0–0.5 s |
| Wall guard clearance (soft / hard) | ~0.45–0.55 m / ~0.15–0.22 m |
| Ultrasonic backup clearance (soft / hard) | 20–25 cm / 15 cm |
| D455 stream | 640×480 @ 30 FPS |

#### Test Results

| **Metric** | **Clockwise** | **Counter-Clockwise** | 
| --- | --- | --- |
| Trials | 30 | 30 | 
| Successful runs | 25/30| 26/30| 
| Success rate | 83.33% | 86.66% | 
| Best / average completion time | 68s | 68s |

## System integration, testing, and risk

### Subsystem interaction

For the current Open Challenge, the D455 depth and BNO055 yaw enter the Jetson control loop. Depth determines wall-distance steering and corner transitions, while yaw independently advances the heading checkpoints used for lap counting. The Jetson sends the resulting steering and speed command to the ESP32, which controls the drive and steering hardware. The final system documentation will add measured sensor-to-actuator latency, ESP32 timeout behavior, power-fault behavior, and validation results.

### Final regression results

| Test | Configuration / Commit | Trials | Acceptance Target | Result | 
|---|---|---:|---|---|
| Open Challenge - clockwise | Final `clockWise.py` configuration | 3 | Complete 3 laps without navigation failure | 3 | 
| Open Challenge - Counterclockwise | Final `counterClockWise.py` configuration | 3 | Complete 3 laps without navigation failure | 3 |
| Obstacle Challenge - Clockwise| Final `obs_clockwise.py` configuration | 3 | Complete obstacle avoidance and navigation | 3 | 
| Obstacle Challenge - Counterclockwise | Final `obs_counterclockwise.py` configuration | 3 | Complete obstacle avoidance and navigation | 3 | 

### Key decisions

| Decision | Alternatives | Trade-off |
| --- | --- | --- |
| Parallel steering | Ackermann steering | Parallel steering is mechanically simpler (fewer linkage points, single servo drives both wheels at equal angle) and easier to build reliably with LEGO Technic parts, but it causes tire scrub in tight turns since both wheels follow arcs of the same radius instead of geometrically correct ones, costing a bit of grip/precision at the sharp corners on the WRO track. |
| LEGO chassis with printed Jetson enclosure | Fully custom 3D-printed chassis / fully LEGO (no custom parts) | Hybrid gives fast, tool-free iteration on the drivetrain/mounting layout (LEGO's modularity) while the printed enclosure protects and rigidly seats the Jetson and its heatsink/fan. But it adds weight and two build systems to keep aligned (LEGO tolerances vs printed tolerances), and the enclosure locks in dimensions once printed. |
| D455 depth wall following | Ultrasonic (HC-SR04 array) | One D455 gives dense depth + RGB across a wide FOV, so wall distance and pillar/obstacle color detection come from a single sensor with clean data. But it's heavier, pricier, and needs meaningfully more compute (USB3 bandwidth + depth processing) than a handful of cheap, lightweight ultrasonic sensors that update faster with near-zero CPU cost. |
| Separate power sources | Single shared 3S battery/single converter feeding both servo and motors | Running two batteries and two converters (buck for servo, buck-boost for motors) adds weight, cost, and wiring/BOM complexity versus one shared source. But it buys electrical isolation (motor noise/current draw can't disturb steering) and, crucially, the buck-boost keeps motor voltage nearly constant across the battery's discharge curve, so PWM-to-speed mapping stays predictable instead of degrading as the pack drains, which matters for consistent and repeatable driving behavior over a full run. | 

### Risk register

| Risk/failure mode | Detection | Mitigation |
| --- | --- | --- |
| Loose LEGO/printed mounting | Found through the print → test-fit → fix cycle on the real robot (e.g. Motor Mount V2's misalignment, see [Our engineering journey](#our-engineering-journey)) | Reoriented/added LEGO-pin mounting points across mount versions (Motor Mount V2→V4, Jetson & Battery Container V2→V3); rounded edges and extra pins added for a more rigid fit | 
| Missing or invalid depth | `roi_distance()` rejects depth outside 0.15–4.00 m and requires ≥50 valid pixels per ROI, returning NaN otherwise; the obstacle-challenge builds additionally track a low-pixel-count flag to distinguish "no data" from "wall too close to resolve" | A NaN/invalid side-wall reading falls back to a gentle search steer (`SEARCH_LEFT_STEER`/`SEARCH_RIGHT_STEER`) instead of driving on a corrupted value; the obstacle builds add rate-limiting (`update_smoothed_left_distance`), EMA smoothing, and hold-last-good logic (`LastGoodHold`) on top | 
| IMU drift/interference | `get_calibration_status()` reports system/gyroscope/accelerometer/magnetometer calibration state at startup; the BNO055 is mounted near chassis center, away from motors and power wiring | Saved calibration offsets are loaded from `bno055_calibration.json` at startup (`bno055_yaw.py`), and heading is zeroed relative to the robot's own start orientation each run rather than assuming a fixed absolute heading | 
| Jetson–ESP32 communication loss | The `ResilientSerial` wrapper (obstacle-challenge code) catches `SerialException`/`OSError` on every serial write and read | On any serial failure, `ResilientSerial` automatically closes and reopens the port in a retry loop until the connection succeeds again, instead of letting the control loop crash | 
| Power sag or actuator stall | Motor/actuator and Jetson/logic loads are supplied from two isolated LiPo + regulator domains (see [Power architecture](#power-architecture)), so a motor-side voltage sag under load cannot brown out the Jetson | Separate power paths prevent actuator current demand from affecting the Jetson/ESP32 logic supply. The servo uses **3S Battery (~11.1V) → XL4015 Buck → 5V → Servo**, while the motors use **3S Battery → XL4016 Buck-Boost → ~11V → TB6612 → DC Motors**. The buck-boost converter maintains approximately 11V, reducing motor-speed variation as battery voltage drops and making PWM-to-speed behavior more predictable. | 

**Detailed evidence:** [Engineering Journal, raw and processed tests, decisions, risks, and final regression results](other/)

## Reproducing IriSight

### Required files and tools

**Hardware** — the full bill of materials with exact models and purchase links is in [Component and interface map](#component-and-interface-map); the three structural 3D-printed parts (STL for printing, STEP for editing) are in [`models/`](models/).

**Software/tools:**
- NVIDIA Jetson Orin Nano flashed with JetPack (Ubuntu 22.04 LTS) and Python 3
- Intel RealSense SDK (`librealsense`) so `pyrealsense2` can talk to the D455
- Arduino IDE (or `arduino-cli`) with the `ESP32Servo` library, to flash [`src/helper_function/ultrasonic_arduino_v2.ino`](src/helper_function/ultrasonic_arduino_v2.ino) onto the ESP32
- The Python packages listed in [Software Installation](#software-installation) below
- `git`, to clone this repository

### Mechanical assembly

1. Build the LEGO Technic chassis with the parallel front-steering linkage and rear drive shaft described in [Mobility and mechanical design](#mobility-and-mechanical-design).
2. Print the three finalized structural parts from [`models/`](models/) at the settings in [`models/README.md`](models/README.md#-print-settings) (PLA, 0.2 mm layers, 20–30% infill): the **Jetson & Battery Container (V3)**, **Rear Motor Mount (V4)**, and **RealSense Camera Mount (V2)**.
3. Pin all three onto the chassis using their LEGO-compatible mounting arms — no screws or brackets are needed for the printed parts themselves.
4. Mount the rear DC motor in the Motor Mount V4 cradle, and use its flat top plate as the shelf for the ESP32 board and buck converter.
5. Mount the two HC-SR04 ultrasonics facing outward on the left/right sides, and the BNO055 near chassis center, away from the motor and high-current wiring — see [Sensor placement and calibration](#sensor-placement-and-calibration).

### Wiring and power-on

Wire every component exactly as shown in the diagram embedded in [Power architecture](#power-architecture) (full source in [`schemes/`](schemes/)), keeping the Jetson/logic battery and the motor/actuator battery on their own separate circuits — do not tie their grounds/rails together except where the diagram shows a shared reference. Double-check the TB6612FNG (IN1=D26, IN2=D25, PWM=D33), servo (D17), and ultrasonic pins (left TRIG=D13/ECHO=D39, right TRIG=D4/ECHO=D16) against the ESP32 firmware before powering on.

Recommended first power-on order: (1) connect the Jetson's battery and confirm the Jetson boots normally with the D455 and BNO055 enumerated; (2) flash and power the ESP32 on its own USB link first and confirm it prints `ESP32 ready` over serial without the motor battery connected; (3) only then connect the motor/actuator battery, and immediately confirm the wheels are off the ground or the vehicle is on a stand before sending any `DRIVE` command.

### Software Installation

The robot's control software runs on the NVIDIA Jetson Orin Nano. The required software and Python packages must be installed before running the vehicle.

#### 1. Clone the repository

```bash
git clone https://github.com/WRO-2026-AUPP/WRO_IriSight.git
```

#### 2. Navigate to the project directory

```bash
cd WRO_IriSight
```

#### 3. Install the required Python packages 

The following packages are required for numerical processing, computer vision, RealSense D455 depth sensing, YOLOv8 object detection, and Jetson-to-ESP32 serial communication.

```bash
pip install numpy
```
```bash
pip install opencv-python
```
```bash
pip install pyrealsense2
```
```bash
pip install ultralytics
```
```bash
pip install pyserial
```
#### 4. Verify the installation

```bash
python3 -c "import cv2, numpy, pyrealsense2, ultralytics, serial; print('All required packages installed successfully.')"
```

### Calibration

Before starting an autonomous run, calibrate the BNO055 and ensure that the saved calibration data is available.

#### Check the calibration file

The saved BNO055 calibration values are stored in:

```text
bno055_calibration.json
```

The calibration data is automatically loaded by ```bno055_yaw.py``` when the BNO055 is initialized.

The system also provides a calibration-status check for the system, gyroscope, accelerometer, and magnetometer.

If the calibration file is missing or invalid, the program will display a warning and continue without the saved calibration.

### Start an Autonomous Run

Select the appropriate control program based on the competition challenge and driving direction. Ensure that the Jetson Orin Nano, D455, BNO055, and ESP32 are connected and ready before starting the autonomous run.

#### 1. Open Challenge — Clockwise

```bash
python3 src/clockWise.py
```

#### 2. Open Challenge — Counter Clockwise

```bash
python3 src/counterClockWise.py
```

#### 3. Obstacle Avoidance Challenge — Clockwise

```bash
python3 src/obs_clockwise.py
```

#### 4. Obstacle Avoidance Challenge — Counter Clockwise

```bash
python3 src/obs_counterclockwise.py
```

### Pre-flight and acceptance test

Before any competition run or timed trial, the following checklist is completed in order:

**Mechanical checks**
- [x] All three 3D-printed mounts (Jetson & Battery Container V3, Motor Mount V4, RealSense Camera Mount V2) are pinned securely with no play
- [x] Front wheels turn freely through the full ±35° steering range with no binding
- [x] Rear wheels and drive shaft spin freely with the motor disconnected (no mechanical drag)
- [x] Vehicle is on a stand with wheels off the ground before any powered test

**Power and connectivity checks**
- [x] Jetson battery connected first; Jetson boots and D455 + BNO055 both enumerate
- [x] ESP32 flashed and powered independently; prints `ESP32 ready` over serial with motor battery disconnected
- [x] Motor/actuator battery connected last, only after the above two checks pass
- [x] TB6612FNG and servo wiring re-checked against pinout (IN1=D26, IN2=D25, PWM=D33, servo=D17)

**Sensor and calibration checks**
- [x] BNO055 calibration status checked (`get_calibration_status()`); saved offsets loaded from `bno055_calibration.json`
- [x] Left/right ultrasonic sensors tested against a known-distance object
- [x] D455 depth stream confirmed at 640×480 @ 30 FPS with no dropped frames

**Software checks**
- [x] Correct challenge/direction script confirmed before start (`clockWise.py`, `counterClockWise.py`, `obs_clockwise.py`, or `obs_counterclockwise.py`)
- [x] Flask diagnostic stream (port 5000) reachable and showing live mode, steering, yaw, and lap count

**Acceptance criteria**

A build is considered competition-ready only if it meets the targets already demonstrated in [Final regression results](#final-regression-results): 3/3 successful trials for both directions of the Open Challenge, and 3/3 successful trials for both directions of the Obstacle Challenge, each with no navigation failure or collision.

## Current limitations and next improvements

| Limitation | Current effect | Planned improvement | Validation target |
| --- | --- | --- | --- |
| Depth sensing limitations | The RealSense D455 does not provide complete visibility from every position and angle. Some areas of the track or obstacles may fall outside the camera's effective field of view or produce unreliable depth measurements. | Improve camera placement and ROI selection, and combine depth sensing with ultrasonic measurements where appropriate. | Maintain reliable wall and obstacle distance measurements throughout the track. |
| Vision sensitivity | YOLOv8 detection performance can be affected by lighting, shadows, reflections, and changes in object appearance. | Expand and improve the training dataset and tune the detection model and confidence thresholds. | Reliably detect the required colored obstacles and parking signal under different lighting conditions. |
| Reaction distance | Obstacles detected too close to the robot may not leave enough distance for safe avoidance. | Improve detection range and trigger avoidance earlier using depth and vision information. | Consistently avoid obstacles without collision during repeated test runs. |
| BNO055 calibration | Accurate yaw-based navigation depends on proper sensor calibration and saved calibration data. | Improve the calibration procedure and maintain reliable saved calibration values. | Achieve consistent yaw readings and checkpoint detection across repeated runs. |
| Heading error | BNO055 yaw measurements may contain small errors or drift, which can affect turn timing and checkpoint detection. | Add heading correction and further tune yaw-based turning thresholds. | Keep heading error within the required navigation tolerance. |
| Controller tuning | Wall-following and obstacle-avoidance performance depends on manually tuned steering gains, target distances, and detection thresholds. | Further tune PD control parameters and navigation thresholds through track testing. | Achieve stable wall following and repeatable obstacle avoidance across multiple runs. |
| Processing load | Running YOLO inference, depth processing, and navigation simultaneously can increase Jetson CPU/GPU usage and introduce latency. | Optimize image/depth processing and reduce unnecessary computation. | Maintain real-time control without noticeable processing delays. |
| Serial communication | The robot depends on reliable communication between the Jetson and ESP32 for timely motor and steering commands. | Improve serial communication handling and add robust error handling. | Maintain reliable command transmission throughout a complete run. |
| Ultrasonic sensing | Ultrasonic readings can be affected by obstacle angle, surface characteristics, interference, and sensor placement. | Improve sensor placement and combine ultrasonic readings with depth information. | Obtain stable distance readings for close-range obstacle detection. |
| Steering geometry | The current prototype uses parallel steering, which can reduce turning accuracy and stability during sharp turns. | Replace the current mechanism with Ackermann steering. | Achieve more accurate and stable cornering with reduced path deviation. |
| Wheel friction | Differences in friction between the wheels and track surface can cause the robot to deviate from its intended path. Changes in surface conditions can also affect turning, acceleration, and stopping performance. | Improve wheel alignment, weight distribution, and mechanical design, and tune control parameters for different track conditions. | Reduce path deviation and achieve consistent movement across repeated runs. |

## MIT License

```
Copyright (c) 2026 Team IriSight

Permission is hereby granted, free of charge, to any person obtaining a copy
of this software and associated documentation files (the "Software"), to deal
in the Software without restriction, including without limitation the rights
to use, copy, modify, merge, publish, distribute, sublicense, and/or sell
copies of the Software, and to permit persons to whom the Software is
furnished to do so, subject to the following conditions:

The above copyright notice and this permission notice shall be included in all
copies or substantial portions of the Software.

THE SOFTWARE IS PROVIDED "AS IS", WITHOUT WARRANTY OF ANY KIND, EXPRESS OR
IMPLIED, INCLUDING BUT NOT LIMITED TO THE WARRANTIES OF MERCHANTABILITY,
FITNESS FOR A PARTICULAR PURPOSE AND NONINFRINGEMENT. IN NO EVENT SHALL THE
AUTHORS OR COPYRIGHT HOLDERS BE LIABLE FOR ANY CLAIM, DAMAGES OR OTHER
LIABILITY, WHETHER IN AN ACTION OF CONTRACT, TORT OR OTHERWISE, ARISING FROM,
OUT OF OR IN CONNECTION WITH THE SOFTWARE OR THE USE OR OTHER DEALINGS IN THE
SOFTWARE.
```

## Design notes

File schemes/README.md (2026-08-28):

# Electromechanical Diagrams

This directory contains one or several schematic diagrams in JPEG, PNG, or PDF format showing the electromechanical architecture of the vehicle. The diagrams illustrate all electronic components, sensors, motors, power sources, and communication connections used in the vehicle.

The vehicle is built around a **Jetson Nano + ESP32 architecture**. The Jetson Nano handles high-level processing, computer vision, sensor interpretation, and decision-making, while the ESP32 handles low-level hardware control such as motor control, steering, and ultrasonic sensors.

The main electrical components are:

* Custom ESP32 development board
* Jetson Nano
* Intel RealSense D455
* Geared DC motors with encoders
* Generic HC-SR04 ultrasonic sensors
* LD-1501MG servo
* BNO055 IMU

The power system consists of:

* 2 × TCB 1100mAh 3S 25C batteries
* XL4015 5V buck converter
* XL4016 11V buck-boost converter

Electrical wiring block diagram

# Main Components

## Custom ESP32 Development Board

custom esp32 board

The custom ESP32 development board is responsible for low-level control of the vehicle. It acts as the interface between the Jetson Nano and the physical actuators and sensors.

The Jetson Nano sends movement commands to the ESP32 through a USB serial connection. The ESP32 receives these commands and converts them into appropriate motor, steering, and other hardware actions.

The board contains **four motor sockets**, allowing up to four DC motors to be connected. The pin configuration below corresponds to **M1**.

### Motor Driver

The board uses **TB6612 H-bridge motor drivers** to control the geared DC motors.

The H-bridge allows the ESP32 to control both the direction and speed of the motors. Motor speed is controlled using PWM, while the two direction pins determine whether the motor rotates forward or backward.

For motor M1, the pin configuration is:

| Function | ESP32 Pin |
| --- | ---: |
| IN1 | 26 |
| IN2 | 25 |
| PWM | 33 |

* **IN1 and IN2** control the motor direction.
* **PWM** controls the motor speed.
* The TB6612 provides the required current handling for the motors rather than having the ESP32 drive the motors directly.

> [!NOTE]
> The board features four motor sockets for DC motors. The pin definition above is for **M1**.

### Steering Servo

The steering system is controlled using the **LD-1501MG servo**.

The servo signal is connected to:

* **Signal:** GPIO 17

The ESP32 generates the PWM control signal required to position the servo. The Jetson Nano determines the desired steering direction and sends the corresponding command to the ESP32.

### Ultrasonic Sensor

The custom ESP32 board also provides connections for the HC-SR04 ultrasonic sensors.

The current pin configuration is:

| Function | ESP32 Pin |
| --- | ---: |
| Trigger  | 13 |
| Echo | 39 |

The ESP32 triggers the ultrasonic sensor and measures the returned echo signal to determine the distance to nearby objects.

The measured distance can then be transmitted back to the Jetson Nano through the USB/UART communication link.

---

## Jetson Nano

Jetson nano

The **Jetson Nano** acts as the main computing and decision-making unit of the vehicle.

It is responsible for:

* Image processing
* Object detection
* Depth processing
* Navigation
* Sensor interpretation
* Generating movement commands for the ESP32

The ESP32 mainly acts as a low-level controller. It receives commands from the Jetson Nano and executes them using the connected motors, servo, and sensors.

### Communication with ESP32

The Jetson Nano communicates with the ESP32 through a **USB cable**.

The custom ESP32 board contains a **CP2101 USB-to-UART converter**. This converter translates the USB communication from the Jetson Nano into UART serial communication that can be processed by the ESP32.

The communication process is:

1. The Jetson Nano processes camera and sensor information.
2. The navigation algorithm determines the desired movement.
3. The Jetson Nano sends a command through USB.
4. The CP2101 converts the USB communication into UART.
5. The ESP32 receives and interprets the command.
6. The ESP32 controls the motors and/or steering servo.
7. Sensor measurements can be sent back to the Jetson Nano.

The Jetson Nano is also directly connected to the **Intel RealSense D455** camera and **BNO055 IMU**.

---

## Intel RealSense D455 Camera

Jetson nano

The **Intel RealSense D455** is the primary vision and depth-sensing device used by the vehicle.

Unlike a standard RGB camera, the RealSense D455 provides both visual information and depth information. This gives the Jetson Nano additional information about the position and distance of objects in the environment.

### RGB Camera

The RGB camera provides conventional visible-light images. These images are processed by the Jetson Nano's computer vision system to identify objects and environmental features.

The camera can be used to detect objects such as:

* Green obstacle boxes
* Red obstacle boxes
* Parking markers
* Walls
* Other objects relevant to navigation

### Depth Camera

The D455 uses stereo depth sensing to estimate the distance between the camera and objects within its field of view.

This allows the system to obtain three-dimensional information from the environment. A detected point can approximately be represented using:

* **X:** horizontal position
* **Y:** vertical position
* **Z:** distance from the camera

The depth information provides additional information for navigation and decision-making on the Jetson Nano.

---

## Geared DC Motors with Encoders

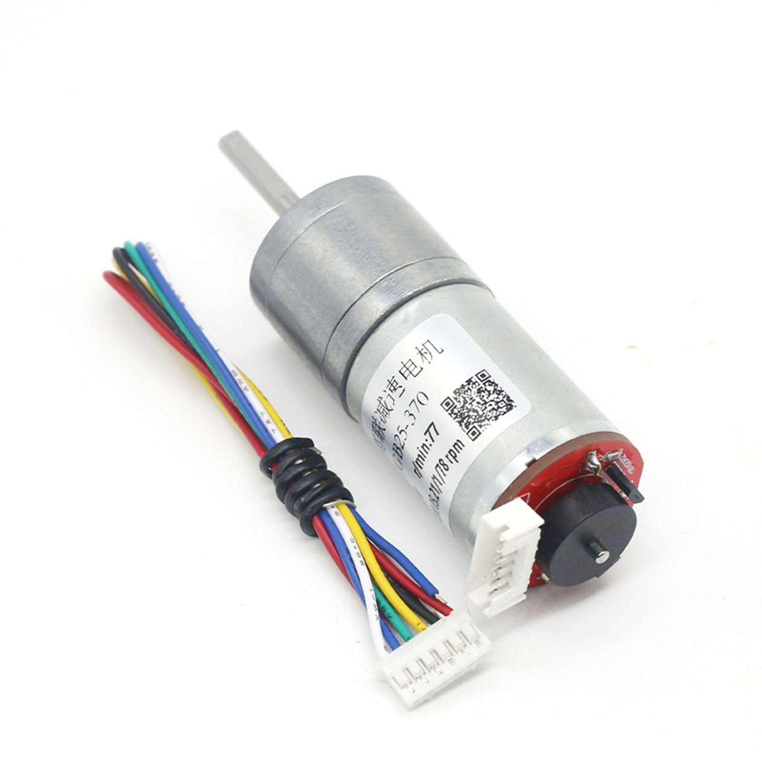
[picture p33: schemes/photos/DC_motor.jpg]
Geared DC motor


The geared DC motors are responsible for driving the **rear axle of the vehicle**.

The motors are controlled by the TB6612 H-bridge drivers on the custom ESP32 board. The ESP32 controls the direction of the motors through the direction pins and controls their speed using PWM.

### Gearbox

The motors contain integrated gearboxes. The gearbox reduces the rotational speed of the motor while increasing the torque available at the output shaft.

The additional torque is important because the motors need to provide enough force to accelerate and move the vehicle reliably.

### Magnetic Encoders

The motors also include magnetic encoders. These encoders can theoretically be used to determine:

* Motor rotation
* Wheel speed
* Distance traveled
* Wheel-based odometry

However, the encoders were not used in the final navigation system.

One reason is that wheel slip can cause encoder-based odometry to become inaccurate. During acceleration, braking, or turning, the wheels may rotate without producing the expected amount of vehicle movement.

In addition, implementing and calibrating an encoder-based odometry system would have required additional development time that was not available during the project.

---

## Generic HC-SR04 Ultrasonic Sensors

ultrasonic sensors

The **HC-SR04 ultrasonic sensors** provide additional short-range distance information to complement the camera-based perception system.

The main decision-making process relies heavily on the camera. However, because the system does not maintain a complete memory of previous camera frames, it can sometimes lack information about walls or obstacles positioned beside the vehicle.

This can become particularly problematic when the vehicle is turning.

### Purpose

The ultrasonic sensors are positioned on the side of the vehicle to detect nearby walls and obstacles.

They provide the navigation system with additional information about:

* The presence of a wall beside the vehicle
* Distance to nearby walls
* Available clearance during turns
* Whether the vehicle is getting too close to an obstacle

This additional information helps the vehicle avoid hitting walls while turning.

### Operation

The HC-SR04 works by sending an ultrasonic pulse and measuring the time required for the reflected signal to return.

The ESP32 communicates with the sensor using:

* **Trigger:** GPIO 13
* **Echo:** GPIO 39

The ESP32 calculates the approximate distance based on the echo time and can then send the measurement to the Jetson Nano.

The data flow is:

**HC-SR04 → ESP32 → USB/UART → Jetson Nano → Navigation algorithm**

---

## LD-1501MG Servo

Servo

The **LD-1501MG servo** is used to control the steering mechanism of the vehicle.

The servo was selected because the generic **9g servos** tested during development were not powerful enough to reliably move the vehicle's steering mechanism.

The LD-1501MG provides greater torque and mechanical strength, allowing it to move and hold the steering mechanism during operation.

### Control

The servo signal is connected to:

* **ESP32 GPIO 17**

The Jetson Nano determines the desired steering direction and sends the corresponding command to the ESP32. The ESP32 then generates the appropriate PWM signal for the servo.

The control path is:

**Jetson Nano → USB → ESP32 → GPIO 17 → LD-1501MG → Steering mechanism**

The servo is powered from the dedicated **5V buck converter** rather than directly from the ESP32.

# Power

The vehicle uses **two TCB 1100mAh 3S 25C batteries**.

The power system is separated between the motor system and the computing/electronics system. This reduces the effect of high motor current and voltage fluctuations on the Jetson Nano and other sensitive electronics.

---

## TCB 1100mAh 3S 25C Battery

25C battery

The vehicle uses two **TCB 1100mAh 3S 25C batteries**.

A 3S battery contains three cells connected in series. Each cell has a nominal voltage of approximately 3.7V, giving the battery a nominal voltage of approximately:

$$
3 \times 3.7V = 11.1V
$$

The battery has a capacity of:

$$
1.1Ah
$$

and a continuous discharge rating of:

$$
25C
$$

The theoretical maximum continuous current is:

$$
1.1Ah \times 25C = 27.5A
$$

Using the nominal battery voltage:

$$
11.1V \times 27.5A \approx 305W
$$

Therefore, the theoretical continuous power capability is approximately **305W**.

> [!NOTE]
> The 305W value is a theoretical value based on the nominal voltage and the 25C discharge rating. Actual available power depends on the battery's voltage, temperature, wiring, connectors, and operating conditions.

### Battery Allocation

The two batteries are used for separate purposes.

**Battery 1 — Motor system**

The first battery supplies the vehicle's motor system and associated power electronics.

**Battery 2 — Computing system**

The second battery supplies the Jetson Nano and other electronics through the appropriate voltage conversion circuitry.

Separating the motor and computing power systems helps reduce the possibility of motor current fluctuations affecting the Jetson Nano.

---

## Buck Converter at 5V

Buck converter

The **XL4015 50W buck converter** is used to provide a stable **5V power supply** for the steering servo.

The 3S battery provides approximately 11.1V nominally, while the servo requires a lower 5V supply. The battery therefore cannot be connected directly to the servo.

The buck converter reduces the battery voltage:

**3S Battery (~11.1V) → XL4015 Buck Converter → 5V → Servo**

The dedicated converter provides the servo with the required voltage while preventing the servo's current demand from being drawn directly through the ESP32's logic circuitry.

---

## Buck-Boost Converter at 11V

Buck converter

The **XL4016 300W buck-boost converter** is used to provide a stable motor supply of approximately **11V**.

The voltage of a battery changes as it is discharged. Without voltage regulation, the motor speed would therefore change even when the same PWM value is being used.

For example:

**Higher battery voltage → Higher motor speed**

**Lower battery voltage → Lower motor speed**

The buck-boost converter maintains the motor supply at approximately 11V, resulting in a more predictable motor response.

The motor power path is:

**3S Battery → XL4016 Buck-Boost Converter → ~11V → TB6612 Motor Driver → DC Motors**

This makes the relationship between PWM commands and motor speed more consistent throughout the usable battery voltage range.

# Overall Electrical Architecture

The complete system can be summarized into three main layers:

### 1. Perception Layer

The **Intel RealSense D455**, **HC-SR04 ultrasonic sensors**, and **BNO055 IMU** provide information about the vehicle's surroundings, obstacles, distance, and orientation.

### 2. Processing and Decision Layer

The **Jetson Nano** processes the sensor information and performs computer vision, object detection, depth processing, and navigation. It determines the desired movement of the vehicle.

### 3. Low-Level Control Layer

The **ESP32** receives commands from the Jetson Nano and controls the physical hardware, including the DC motors and steering servo. It also reads the ultrasonic sensors and sends their measurements back to the Jetson Nano.

The overall control flow is:

**Sensors → Jetson Nano → Decision → ESP32 → Actuators**

while sensor feedback follows:

**Sensors → ESP32/Jetson Nano → Navigation System**

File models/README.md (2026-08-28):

# 🧩 3D Models & Mechanical Components

This directory contains the CAD design files for IriSight's 3D-printed structural components — the parts that hold the electronics and mechanics onto the LEGO-based chassis. Each design is provided as a `.png` render (for quick viewing), a `.stl` (for slicing/printing), and a `.step` (for editing in CAD software).

This is also where our hardware journey actually started. Before any wiring or code, we needed a way to physically mount components onto the chassis — so the first thing we designed was a combined **Jetson + Battery container**. As more structural parts are designed, they are documented here as their own component, following the same format.

---

## 📂 File structure

```
models/
├── png/                          # Quick-view renders
├── STL_file/                     # Print-ready meshes
└── STEP_file/                    # Editable CAD source
```

---

## 📑 Table of Contents

This document currently covers all of our 3D-printed structural parts:

| # | Component | Status |
| --- | --- | --- |
| 1 | [Jetson & Battery Container](#component-1) | Finalized (V3) |
| 2 | [Rear Motor Mount](#component-2) | Finalized (V4) |
| 3 | [RealSense Camera Mount](#component-3) | Finalized (V2) |
| 4 | [Print Settings](#print-settings) | Finalized (V1) |

---

# 🖥️ Component 1 — Jetson & Battery Container

**Status:** Final design complete (V3)

## 📅 Design timeline

| Date | Milestone | What we did | What we learned | Next step |
| --- | --- | --- | --- | --- |
| 2026-May-27 | **V1 — Concept design** | Rough-drew the first version of a combined Jetson + battery mounting container in CAD, sized from measured/estimated component dimensions. | First pass at a shape that could hold both units without a full assembly test yet. | Print a small section to verify the measurements before committing to a full print. |
| 2026-May-27 | **P1 — Prototype test cut** | Instead of printing the entire V1 model, we cut out and printed just a small section of it to cheaply test whether the measured unit dimensions actually matched the real Jetson and battery. | The test piece came back with a small dimensional error — the fit was close, but not exact. **[TODO: quantify the error, e.g. "compartment was ~Xmm too narrow"]** | Adjust the V1 dimensions based on the P1 measurement error and prepare a corrected version. |
| 2026-June-02 | **V2 — LEGO-compatible redesign** | Redesigned the container to fit and connect with LEGO parts directly, inspired by the LEGO Beam Frame geometry. Added a row of LEGO-pin-spaced holes along the base/side so the container pins straight onto the LEGO chassis. | Since the rest of the chassis is LEGO-based, giving the printed part the same pin connection system makes it mount and reposition like any other LEGO piece — no separate brackets or screws needed. | **[TODO: next step — test-fit V2 pins into the actual LEGO chassis and record the result]** |
| 2026-June-03 | **V3 — Final design** | Refined V2 into the final version: rounded/filleted the exposed corners and edges, and added extra LEGO-pin holes on the front face for a more rigid mount. | Rounded edges reduce sharp corners that are more prone to print defects and snagging, and the extra pin holes give the container more mounting points on the chassis. | Container design is finalized (V3). Move on to designing the rear motor mount. |

> We test-print small sections before committing to a full-size print specifically to catch dimensional errors early without wasting filament/time on a full-size reprint. This is why P1 exists as a separate, smaller file rather than a full print of V1.

## 🖼️ V1 — Initial Design

<div align="center">
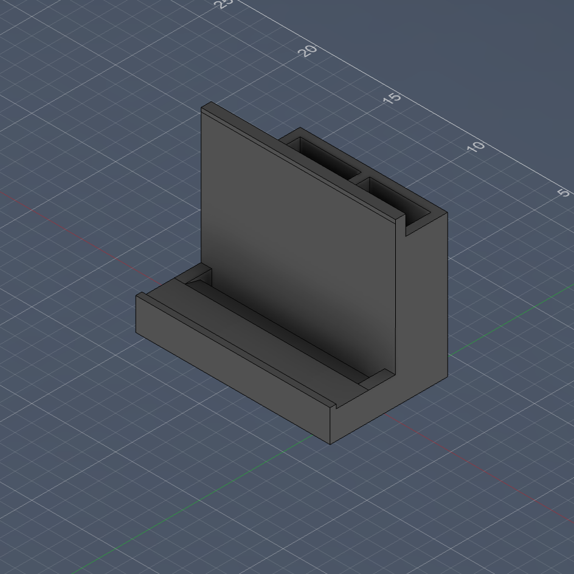
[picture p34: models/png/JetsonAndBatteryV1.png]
JetsonAndBatteryV1 CAD render
  
  <p><em>V1 — combined Jetson + battery container, first CAD draft (2026-May-27)</em></p>
</div>

The V1 design is an L-shaped container with two rectangular compartments sized to hold the Jetson and its battery side by side, with a base flange for mounting to the LEGO chassis.

**Files**

| Format | Link |
| --- | --- |
| PNG | [`JetsonAndBatteryV1.png`](./png/JetsonAndBatteryV1.png) |
| STL | [`JetsonAndBatteryV1.stl`](./STL_file/JetsonAndBatteryV1.stl) |
| STEP | [`JetsonAndBatteryV1.step`](./STEP_file/JetsonAndBatteryV1.step) |

## 🖼️ P1 — Prototype Test Cut

<div align="center">
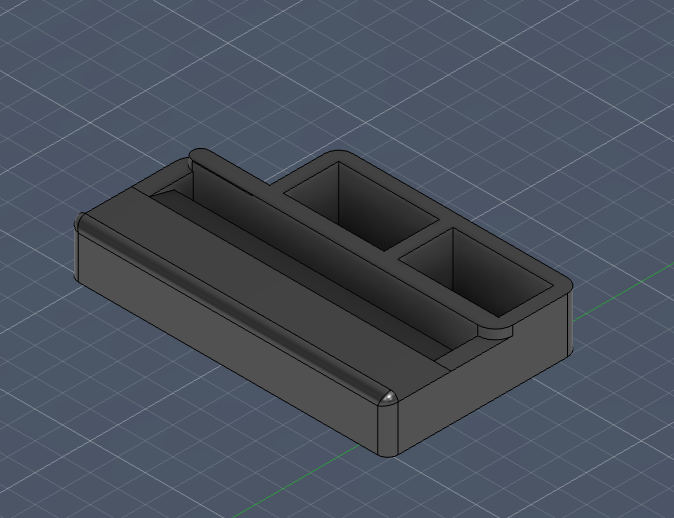
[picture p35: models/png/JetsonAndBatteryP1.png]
JetsonAndBatteryP1 CAD render
  
  <p><em>P1 — a small cut-out section of V1, printed to test-fit real components (2026-May-27)</em></p>
</div>

P1 is not a separate design — it's a small slice of the V1 geometry (one corner/compartment section), printed on its own to cheaply verify that the compartment dimensions matched the real Jetson and battery before committing to printing the full V1 shape.

**Files**

| Format | Link |
| --- | --- |
| PNG | [`JetsonAndBatteryP1.png`](./png/JetsonAndBatteryP1.png) |
| STL | [`JetsonAndBatteryP1.stl`](./STL_file/JetsonAndBatteryP1.stl) |
| STEP | [`JetsonAndBatteryP1.step`](./STEP_file/JetsonAndBatteryP1.step) |

## 🖼️ V2 — LEGO-Compatible Redesign

<div align="center">
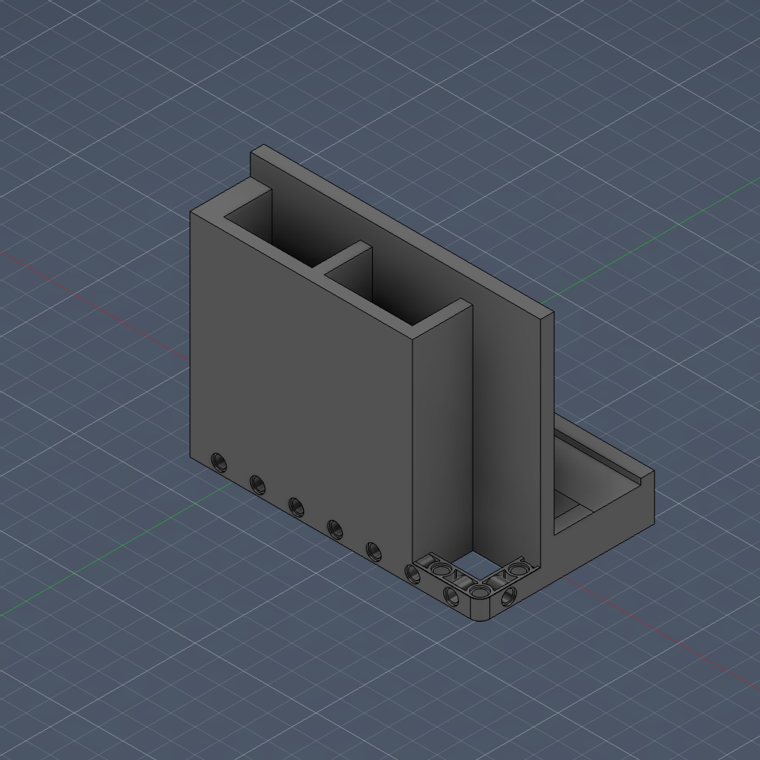
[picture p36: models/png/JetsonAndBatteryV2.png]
JetsonAndBatteryV2 CAD render
  
  <p><em>V2 — same two-compartment Jetson + battery layout as V1, redesigned with LEGO-pin-spaced holes for direct chassis mounting (2026-June-02)</em></p>
</div>

V2 keeps the V1 layout (two compartments for the Jetson and battery) but reworks the mounting method. We are building the rest of the chassis out of LEGO parts, so rather than mounting the printed container with separate brackets or screws, we redesigned it to fit and connect with LEGO parts directly — adding a row of holes spaced and sized to match a standard LEGO Technic beam, so the container can be pinned straight onto the chassis. The idea came directly from studying the LEGO Beam Frame geometry below.

**Files**

| Format | Link |
| --- | --- |
| PNG | [`JetsonAndBatteryV2.png`](./png/JetsonAndBatteryV2.png) |
| STL | [`JetsonAndBatteryV2.stl`](./STL_file/JetsonAndBatteryV2.stl) |
| STEP | [`JetsonAndBatteryV2.step`](./STEP_file/JetsonAndBatteryV2.step) |

## 🖼️ V3 — Final Design

<div align="center">
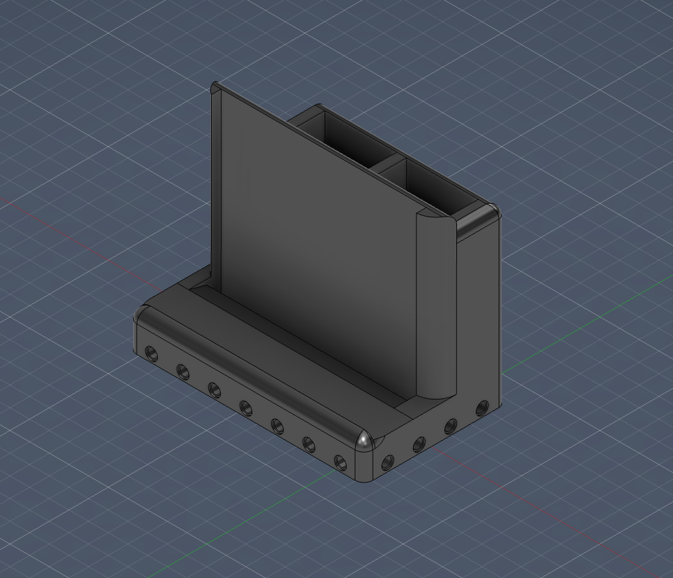
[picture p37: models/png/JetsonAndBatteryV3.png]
JetsonAndBatteryV3 CAD render
  
  <p><em>V3 — final revision: rounded corners/edges and extra LEGO-pin holes for a more rigid mount (2026-June-03)</em></p>
</div>

V3 is the final version of the Jetson + battery container. It keeps V2's two-compartment layout and LEGO-pin mounting, and refines it: exposed corners and edges are rounded/filleted, and extra LEGO-pin holes were added to the front face for a more rigid mount to the chassis. Rounding the edges also makes the part cleaner to 3D print and less likely to chip or snag against other parts.

**Files**

| Format | Link |
| --- | --- |
| PNG | [`JetsonAndBatteryV3.png`](./png/JetsonAndBatteryV3.png) |
| STL | [`JetsonAndBatteryV3.stl`](./STL_file/JetsonAndBatteryV3.stl) |
| STEP | [`JetsonAndBatteryV3.step`](./STEP_file/JetsonAndBatteryV3.step) |

### 📐 Final Engineering Blueprint

<div align="center">
  Jetson and Battery Container engineering blueprint
  <p><em>Final blueprint sheet — top, right-side, front, and isometric views with full dimensions and material properties</em></p>
</div>

This blueprint is the final technical reference for the container: orthographic top/side/front views with dimensions in millimeters, plus an isometric view, generated directly from the final V3 CAD model with the correct print material assigned.

| Property | Value |
| --- | --- |
| Material | PLA (3D print), density 1.24 g/cm³ |
| Volume | 222.051 cm³ |
| Mass (at 100% infill) | 275.3 g |
| Bounding box (L × W × H) | 120.0 × 72.2 × 96.9 mm |
| Surface area | 737.111 cm² |

## 🖼️ Reference — LEGO Beam Frame

<div align="center">
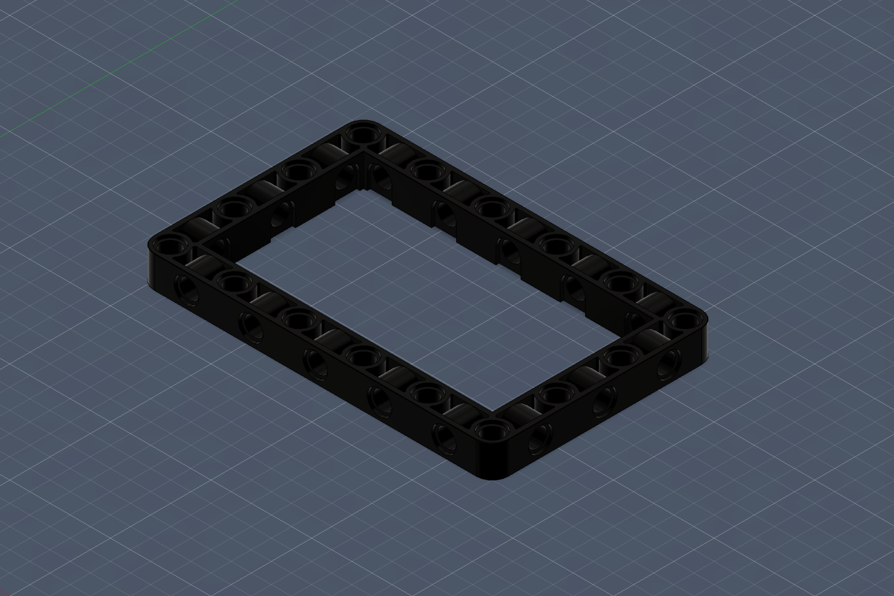
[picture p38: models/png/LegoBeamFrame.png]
LegoBeamFrame CAD render
  
  <p><em>LEGO Beam Frame — reference geometry used to match V2/V3's hole spacing and size to standard LEGO Technic pins</em></p>
</div>

This is a CAD model of a standard LEGO Technic beam frame, modeled as a reference so the container's mounting holes could be designed to the same pin spacing and diameter as real LEGO parts — this is what makes V2/V3 a drop-in fit on the LEGO chassis instead of just a visually similar hole pattern.

**Files**

| Format | Link |
| --- | --- |
| PNG | [`LegoBeamFrame.png`](./png/LegoBeamFrame.png) |
| STL | [`LegoBeamFrame.stl`](./STL_file/LegoBeamFrame.stl) |
| STEP | [`LegoBeamFrame.step`](./STEP_file/LegoBeamFrame.step) |

---

# ⚙️ Component 2 — Rear Motor Mount

**Status:** Final design complete (V4)

This section documents the CAD design of the mount that holds the rear DC gear-motor to the chassis. It went through four iterations: a basic block-shaped mount, a LEGO-connectable redesign that failed a physical fit test, a corrected version, and a final version that also carries the rear electronics.

## 📅 Design timeline

| Date | Milestone | What we did | What we learned | Next step |
| --- | --- | --- | --- | --- |
| 2026-May-26 | **V1 — Basic block mount** | Drew the first, very basic version: a solid block with a U-shaped cradle for the motor body and a hole pattern to bolt the motor to it. No LEGO connection yet. | Established the core motor cradle shape before worrying about how it attaches to the chassis. | Add a way to connect the mount to the LEGO chassis. |
| 2026-May-29 | **V2 — LEGO-connectable redesign** | Redesigned V1 with two LEGO Technic beam arms sticking straight up on a **vertical axis**, inspired by the `LegoAngleBeam` reference part, so the mount could pin directly onto the LEGO chassis like the Jetson/battery container does. | We printed and test-fit V2 on the actual robot. It was **completely wrong** — with the vertical-axis arms, the mount ended up misaligned with the front wheel/steering assembly, which affected the robot's turning. | Reorient the LEGO connection arms so the mount no longer conflicts with the front wheel/steering geometry. |
| 2026-June-12 | **V3 — Corrected orientation** | Changed the LEGO-connecting arms from a vertical axis to an angled orientation, both to fix the front-wheel misalignment found in V2 and to make the arms easier to mount in general. | Reorienting the connection geometry (not just resizing it) was what actually fixed the misalignment — a purely dimensional fix would not have solved a directional/alignment problem. | Confirm the fix, then add a place to mount the rear electronics. |
| 2026-June-14 | **V4 — Final design** | Final version: reworked the LEGO mounting again for a better connection, and added a flat top plate as a mounting shelf for rear electronics (ESP32 board, buck converter, etc.), with some extra workaround geometry to make everything fit together. | Combining the motor mount with the electronics shelf needed some non-obvious workarounds to make both fit without interfering with each other, but it worked out. | Design finalized (V4). Test-fit the electronics on the plate and confirm clearances. |

> V2 is a good example of why we physically print and test-fit every mechanical iteration instead of trusting the CAD render alone: the misalignment with the front wheel was only obvious once the part was mounted on the real robot, not in the CAD viewport.

## 🖼️ V1 — Basic Block Mount

<div align="center">
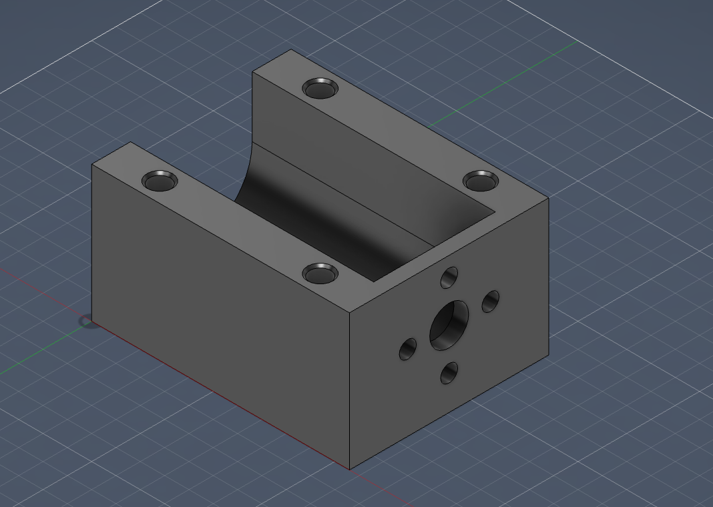
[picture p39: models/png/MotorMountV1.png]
MotorMountV1 CAD render
  
  <p><em>V1 — basic block motor cradle with bolt pattern, no LEGO connection yet (2026-May-26)</em></p>
</div>

The first version is a simple solid block with a curved U-channel cradle that the motor body sits in, plus a circular bolt/shaft hole pattern on the front face. This established the core motor-holding shape before any chassis-connection method was designed.

**Files**

| Format | Link |
| --- | --- |
| PNG | [`MotorMountV1.png`](./png/MotorMountV1.png) |
| STL | [`MotorMountV1.stl`](./STL_file/MotorMountV1.stl) |
| STEP | [`MotorMountV1.step`](./STEP_file/MotorMountV1.step) |

## 🖼️ V2 — LEGO-Connectable Redesign (failed fit test)

<div align="center">
  MotorMountV2 CAD render
  <p><em>V2 — two vertical-axis LEGO Technic arms added, inspired by the LEGO Angle Beam (2026-May-29)</em></p>
</div>

V2 keeps the V1 motor cradle but adds two LEGO Technic beam arms standing straight up on a vertical axis, so the mount could pin directly onto the LEGO chassis — the same idea used for the Jetson & Battery Container, inspired by studying a LEGO angle beam (see the reference part below).

**This version failed its physical test.** Once printed and assembled onto the real robot, the vertical-axis arms put the mount out of alignment with the front wheel/steering assembly, which affected the robot's turning. This is what drove the orientation change in V3.

**Files**

| Format | Link |
| --- | --- |
| PNG | [`MotorMountV2.png`](./png/MotorMountV2.png) |
| STL | [`MotorMountV2.stl`](./STL_file/MotorMountV2.stl) |
| STEP | [`MotorMountV2.step`](./STEP_file/MotorMountV2.step) |

## 🖼️ V3 — Corrected Orientation

<div align="center">
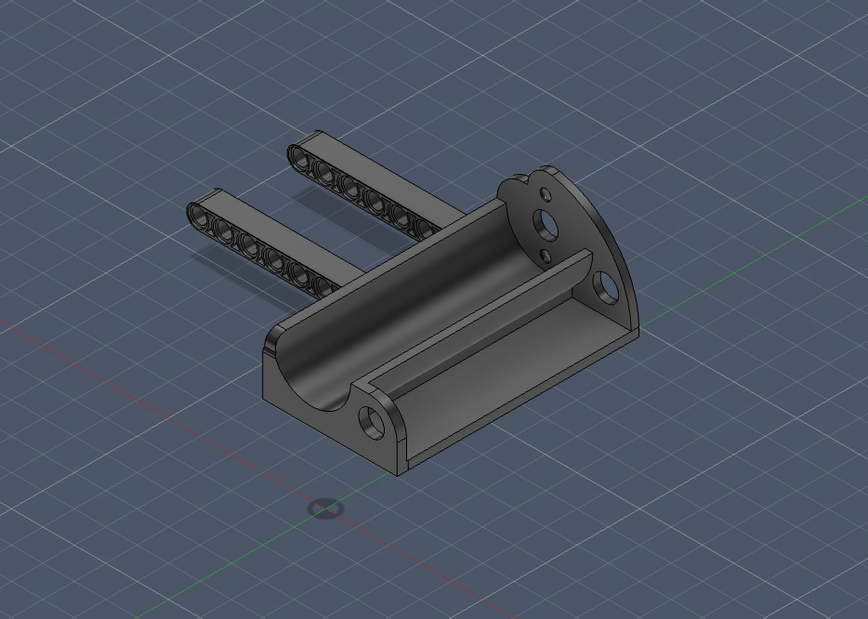
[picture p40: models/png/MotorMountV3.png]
MotorMountV3 CAD render
  
  <p><em>V3 — LEGO arms reoriented away from the vertical axis, fixing the V2 front-wheel misalignment (2026-June-12)</em></p>
</div>

V3 changes the orientation of the LEGO connection arms away from the vertical axis used in V2. This fixed the front-wheel/steering misalignment found when V2 was test-fit on the robot, and also made the arms easier to mount in general.

**Files**

| Format | Link |
| --- | --- |
| PNG | [`MotorMountV3.png`](./png/MotorMountV3.png) |
| STL | [`MotorMountV3.stl`](./STL_file/MotorMountV3.stl) |
| STEP | [`MotorMountV3.step`](./STEP_file/MotorMountV3.step) |

## 🖼️ V4 — Final Design

<div align="center">
  MotorMountV4 CAD render
  <p><em>V4 — final version: reworked LEGO mounting plus a flat top plate to carry the rear electronics (2026-June-14)</em></p>
</div>

V4 is the final motor mount design. It reworks the LEGO connection once more for a better mount, and adds a flat plate on top to serve as a mounting shelf for the rear electronics — the ESP32 board, buck converter, and similar components — with some extra workaround geometry added to make the motor cradle, LEGO mounting, and electronics shelf all fit together on one part. This was the version selected for the final robot.

**Files**

| Format | Link |
| --- | --- |
| PNG | [`MotorMountV4.png`](./png/MotorMountV4.png) |
| STL | [`MotorMountV4.stl`](./STL_file/MotorMountV4.stl) |
| STEP | [`MotorMountV4.step`](./STEP_file/MotorMountV4.step) |

### 📐 Final Engineering Blueprint

<div align="center">
  Motor Mount engineering blueprint
  <p><em>Final blueprint sheet — top, right-side, front, and isometric views with full dimensions and material properties</em></p>
</div>

| Property | Value |
| --- | --- |
| Material | PLA (3D print), density 1.24 g/cm³ |
| Volume | 113.346 cm³ |
| Mass (at 100% infill) | 140.5 g |
| Bounding box (L × W × H) | 72.2 × 120.0 × 56.7 mm |
| Surface area | 502.699 cm² |

## 🖼️ Reference — LEGO Angle Beam

<div align="center">
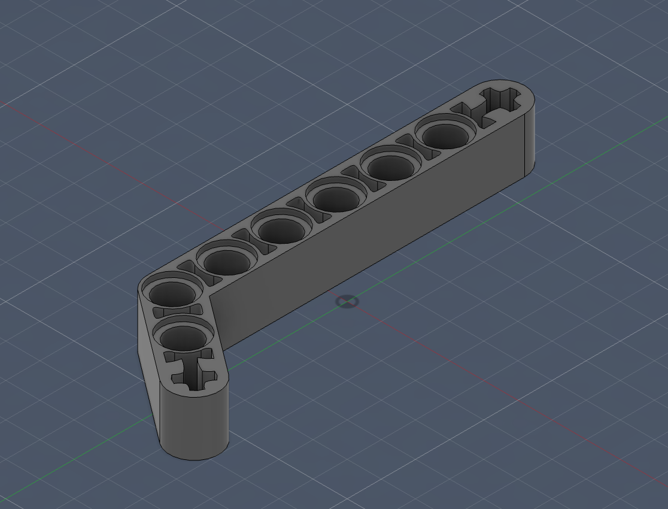
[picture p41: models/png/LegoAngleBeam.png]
LegoAngleBeam CAD render
  
  <p><em>LEGO Angle Beam — reference geometry that inspired the LEGO-connectable arms on V2–V4</em></p>
</div>

This is a CAD model of a standard LEGO Technic angle beam, modeled as a reference for the LEGO-pin spacing and hole sizing used on the motor mount's connection arms from V2 onward.

**Files**

| Format | Link |
| --- | --- |
| PNG | [`LegoAngleBeam.png`](./png/LegoAngleBeam.png) |
| STL | [`LegoAngleBeam.stl`](./STL_file/LegoAngleBeam.stl) |
| STEP | [`LegoAngleBeam.step`](./STEP_file/LegoAngleBeam.step) |

---

# 📷 Component 3 — RealSense Camera Mount

**Status:** Final design complete (V2)

This section documents the mount that holds the Intel RealSense D455 to the chassis via three LEGO Technic pin arms. It only took two iterations — the second was a small but important change to how the mount connects to the LEGO chassis, found by printing and test-fitting both versions.

## 📅 Design timeline

| Date | Milestone | What we did | What we learned | Next step |
| --- | --- | --- | --- | --- |
| 2026-June-05 | **V1 — Same-direction mounting holes** | Designed a mount with three LEGO Technic pin arms hanging below the camera bar, with each arm's pin holes facing the **same direction the RealSense camera faces**. | — | Print and test-fit alongside a second orientation. |
| 2026-June-09 | **V2 — Facing mounting holes** | Rotated the pin holes on the three arms so they **face each other** (inward) instead of facing the same direction as the camera. | We printed and physically tested both V1 and V2. V2 was easier to mount onto the LEGO chassis and made a more robust connection than V1. | Design finalized (V2), selected for the final robot. |

> The only geometric difference between V1 and V2 is the direction the LEGO pin holes face on the three mounting arms — everything else (camera bar, hole spacing, arm count) is identical. This isolates the comparison to a single variable, which is why we can be confident the mounting-hole orientation is what made V2 more robust, not some other change.

## 🖼️ V1 — Same-Direction Mounting Holes

<div align="center">
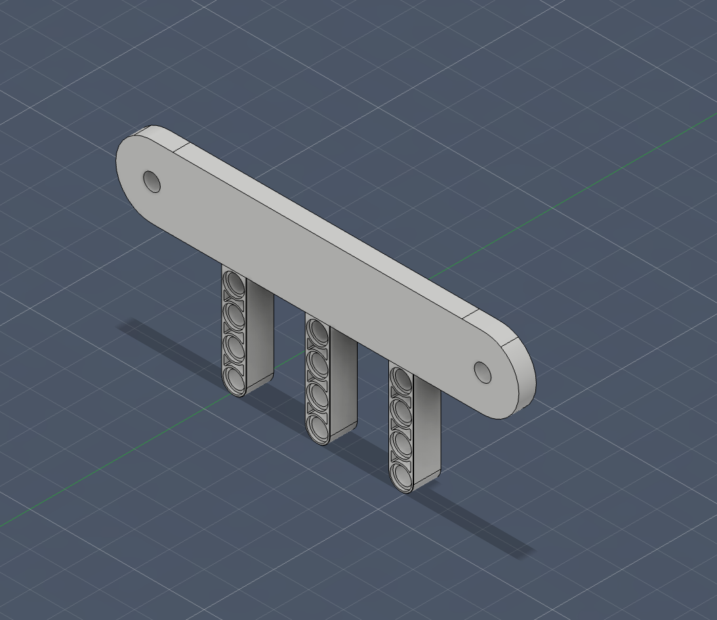
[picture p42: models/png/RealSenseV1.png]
RealSenseV1 CAD render
  
  <p><em>V1 — three LEGO pin arms with holes facing the same direction as the camera (2026-June-05)</em></p>
</div>

A long bar with two mounting holes for the RealSense D455 itself, supported by three LEGO Technic pin arms hanging below it. In V1, each arm's pin holes face the same direction the camera faces.

**Files**

| Format | Link |
| --- | --- |
| PNG | [`RealSenseV1.png`](./png/RealSenseV1.png) |
| STL | [`RealSenseV1.stl`](./STL_file/RealSenseV1.stl) |
| STEP | [`RealSenseV1.step`](./STEP_file/RealSenseV1.step) |

## 🖼️ V2 — Final Design (Facing Mounting Holes)

<div align="center">
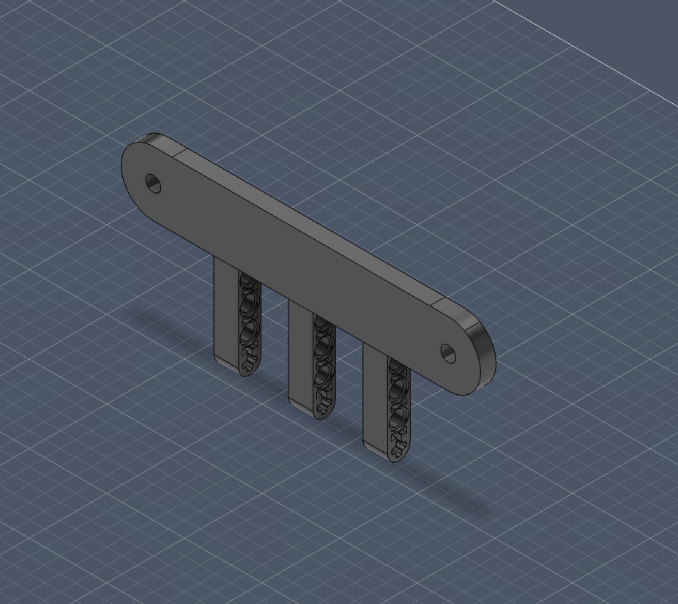
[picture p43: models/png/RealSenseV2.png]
RealSenseV2 CAD render
  
  <p><em>V2 — final design: pin holes on the three arms rotated to face each other (2026-June-09)</em></p>
</div>

Same camera bar and three-arm layout as V1, but the pin holes on the arms are rotated to face each other instead of facing the same direction as the camera. Testing both printed versions on the robot showed this orientation mounts more easily onto the LEGO chassis and holds more robustly, so V2 was selected as the final design.

**Files**

| Format | Link |
| --- | --- |
| PNG | [`RealSenseV2.png`](./png/RealSenseV2.png) |
| STL | [`RealSenseV2.stl`](./STL_file/RealSenseV2.stl) |
| STEP | [`RealSenseV2.step`](./STEP_file/RealSenseV2.step) |

### 📐 Final Engineering Blueprint

<div align="center">
  RealSense Camera Mount engineering blueprint
  <p><em>Final blueprint sheet — top, right-side, front, and isometric views with full dimensions and material properties</em></p>
</div>

| Property | Value |
| --- | --- |
| Material | PLA (3D print), density 1.24 g/cm³ |
| Volume | 14.799 cm³ |
| Mass (at 100% infill) | 18.4 g |
| Bounding box (L × W × H) | 115.7 × 7.2 × 51.9 mm |
| Surface area | 108.56 cm² |

---

## 🖨️ Print Settings

All three components above (Jetson & Battery Container, Rear Motor Mount, RealSense Camera Mount) are printed with the same settings:

| Setting | Value |
| --- | --- |
| Material | PLA |
| Layer height | 0.2 mm (standard quality) |
| Infill | 20–30% for structural components |
| Support | Required for overhangs greater than 60° |

> These are the settings we actually print with, which is also why each blueprint's mass value (computed at 100% infill) is an upper bound rather than the real printed mass — the real, 20–30%-infill parts weigh less.

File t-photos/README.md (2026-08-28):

Team's photos
====
Official photographic documentation of Team IriSight from the American University of Phnom Penh (AUPP).

## About Our Team
Team Photo

_Team Photo - From left to right: Kimchour, Panha (Coach), Nita, and Muyleang._

## Team Members
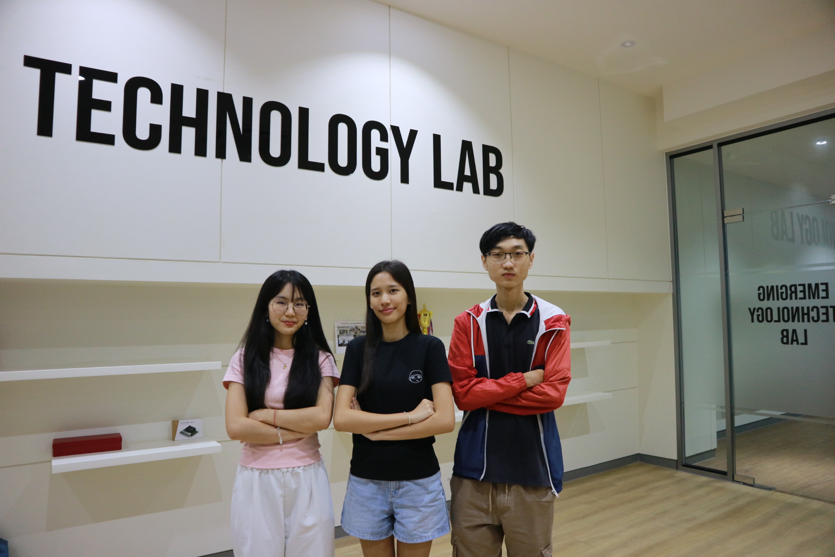
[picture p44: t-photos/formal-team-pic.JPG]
Team Members


### Member 1 — Ponlork Ponita

**Role:** 3D Design & Mechanical Engineer

**Introduction:**

Focused on the vehicle’s mechanical structure, CAD design, and 3D-printed components.

**Individual Contribution:**

* Led CAD design and 3D modeling of the Jetson, battery, motor, and camera mounts.
* Iterated through print-and-test fits to create a secure LEGO-compatible chassis.
* Created detailed blueprints documenting dimensions and materials.

### Member 2 — Taing Muyleang

**Role:** Electrical & Sensor Engineer

**Introduction:**

Responsible for the vehicle’s electrical system, power distribution, and sensor integration.

**Individual Contribution:**

* Developed the ESP32 firmware and Jetson control software.
* Implemented communication between microcontrollers and compute modules.
* Maintained the codebase and ensured reliable system integration.

### Member 3 — Luy Kimchour 

**Role:** Embedded & Software Engineer

**Introduction:**

Focused on system programming, communication between hardware, and overall software integration.

**Individual Contribution:**

* Provided technical guidance in mechanical, electrical, and software development.
* Mentored the team through testing, documentation, and integration.
* Advised on CAD optimization and autonomous vehicle control.

## Coach

### Coach — Chamroeun Vireakpanha

**Introduction:**

Guided the team with technical expertise, testing strategies, and competition-focused problem solving.

**Contribution:**

* Provided technical guidance in mechanical, electrical, and software development.
* Mentored the team through testing, documentation, and integration.
* Advised on CAD optimization and autonomous vehicle control.

## Team Contribution

Although each member has individual responsibilities, we work together throughout the project. Our combined contributions include:

* **Planning & Research**: Developing ideas and understanding the project requirements.
* **Design & Development**: Building and improving the project together.
* **Testing & Problem Solving**: Identifying issues and working together to find solutions.
* **Documentation**: Recording our progress, decisions, and results.

## Teamwork
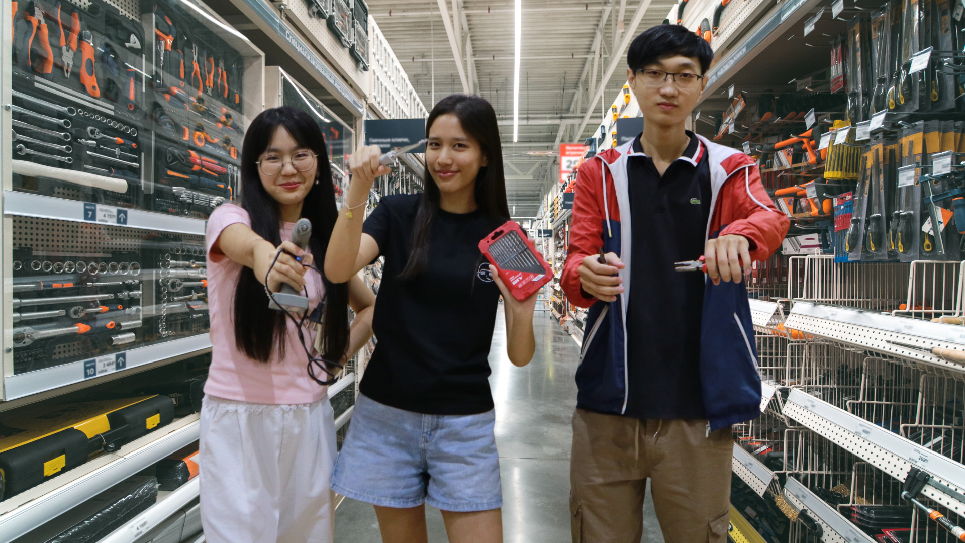
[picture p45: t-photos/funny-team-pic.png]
Teamwork


Our team's success comes from combining our individual skills and supporting one another. Each member contributes to different parts of the project while collaborating on important decisions and challenges. With the guidance of our coach, we continuously learn, improve, and work toward achieving our common goal.

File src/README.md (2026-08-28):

💻 Control software
====
This directory contains the control software used by our vehicle to participate in the **WRO 2026 Future Engineers** competition, developed entirely by our team. It includes all code, trained models, and dependency information required to build and run the robot's autonomous behavior for both the Open Challenge and Obstacle Avoidance rounds.

## 🧠 Our Approach

Our robot navigates using the Intel RealSense D455 depth camera as its primary spatial sensor, supplemented by the BNO055 IMU for heading and, in the obstacle round, ultrasonic sensors for redundant close-range sensing.

We chose wall following as our core navigation strategy for a simple reason: with a camera as the primary spatial sensor, walls are the most consistent and reliable reference we can measure. They give a stable, low-noise signal that doesn't depend on track markings or lighting conditions the way pure visual line-following would. This choice also produces smooth, repeatable paths and keeps the robot at a safe, predictable standoff from the track boundary, even with small variations in how the track is physically built.

Because our entire navigation strategy rests on a single depth signal, most of our engineering effort went into making that signal as clean and responsive as possible — filtering noisy depth readings, using median sampling instead of raw pixel reads, and tuning a PD controller so the robot reacts quickly to error without oscillating. The Jetson handles all sensing, vision, and decision-making; it then sends simple, low-level drive commands to an ESP32 over serial, which is responsible only for actually driving the motors and steering servo.

## 🤖 AI Model

While the Open Challenge relies purely on depth-based wall following, the Obstacle Avoidance round additionally requires the robot to recognize and react to colored pillars and the parking signal. For this, we use a custom-trained **YOLOv8n** object detection model, which is the primary way our robot perceives obstacles.

#### 🎯 What it detects

| Class | Detect Object | Robot Action |
|---|---|---|
| 0 | **Green Obstacle Pillar** (`greenbox`) | Robot turns/passes to the **left** |
| 1 | **Red Obstacle Pillar** (`redbox`) | Robot turns/passes to the **right** |
| 2 | **Parking Marker** (`xparking`) | Robot detects and aligns with the **parking space** |

#### 🏋️ Training details

- **Base architecture:** YOLOv8n (nano) — chosen for its speed/accuracy tradeoff, so it can run in real time on the Jetson alongside the depth-processing pipeline.
- **Input size:** 640×640
- **Epochs:** 100 (batch size 8, auto optimizer, lr0 = 0.01)
- **Dataset:** Custom-labeled images of the competition field's red/green pillars and the parking marker, captured under varied lighting and distances.
- **Validation performance:** precision ≈ 0.997, recall ≈ 0.985, mAP@50 ≈ 0.995, mAP@50-95 ≈ 0.928.
- **Weights file:** `best1.pt` — the best checkpoint by validation fitness, used directly for inference on the robot.

#### ⚙️ How it fits into the pipeline

1. **Color frame → YOLO inference.** Each color frame from the RealSense D455 is passed through the YOLOv8 model to detect and classify `greenbox`, `redbox`, and `xparking` instances, returning bounding boxes and confidence scores.
2. **Depth fusion.** The pixel location of each detected box is cross-referenced with the aligned depth frame to estimate the obstacle's real-world distance and lateral offset, not just its position in the 2D image.
3. **Decision logic.** Based on the detected class, the robot computes a steering offset to pass green pillars on the right and red pillars on the left, while the underlying wall-following PD controller continues to handle smooth trajectory correction.
4. **Parking maneuver.** Once `xparking` is detected and the robot has completed the required laps, detections of this class are used to align the robot with the parking space and trigger the final parking sequence.
5. **Ultrasonic backup.** Ultrasonic sensors provide redundant close-range confirmation so a missed or late detection doesn't result in a collision.

Because object detection only needs to run during the Obstacle Avoidance round, YOLO inference is disabled entirely during the Open Challenge to save compute and keep the depth-based control loop running at full speed.

### 🏁 Open Challenge
#### 📋 Challenge Requirements

The Open Challenge requires the robot to autonomously complete 3 laps around the track, staying within track boundaries and avoiding contact with the walls. There are no pillars or fixed obstacles in this round — the only challenge is smooth, accurate navigation and reliable lap counting.

Since the direction of travel (clockwise or counter-clockwise) is only revealed just before the run starts, our robot needs to be able to run in either direction. We solved this by building two interchangeable driving programs:

| Mode | Wall Followed | Turn at Corners |
|---|---|---|
| `clockWise.py` | Left wall | Turns **right** |
| `counterClockWise.py` | Right wall | Turns **left** |

#### 🧭 Navigation Per File

**Left Wall Following (clockWise.py)**
- Follows the left wall and uses the LEFT ROI to keep a consistent distance.
- If the robot is too far from the left wall, it steers right toward the wall.
- If it is too close, it steers left away from the wall.
- At a corner, it makes a fixed right turn (TURN_STEER = +30°) until the path ahead is clear.
- If the left wall cannot be detected, it gently steers left to search for it again.
- Lap checkpoints are detected in the order 90° → 180° → 270° → 0°.

**Right Wall Following (counterClockWise.py)**
- Follows the right wall and uses the RIGHT ROI to keep a consistent distance.
- If the robot is too far from the right wall, it steers right toward the wall.
- If it is too close, it steers left away from the wall.
- At a corner, it makes a fixed left turn (TURN_STEER = −32°) until the path ahead is clear.
- If the right wall cannot be detected, it gently steers right to search for it again.
- Lap checkpoints are detected in the order 270° → 180° → 90° → 0°.

#### 🎯 Our Strategy

1. **Depth camera for navigation, IMU for lap counting** <br>
   In the Open Challenge, steering relies entirely on the RealSense D455 depth stream. YOLO and ultrasonic sensors are not used because there are no pillars to detect. The BNO055 IMU runs
   alongside the camera and is used only to track heading and count laps, not for steering.
3. **Two regions of interest (ROIs) are read from each depth frame** <br>
- FRONT ROI: Centered in the frame and used to detect an approaching wall or corner.
- SIDE ROI: Located on the left or right depending on the mode, and used to measure the robot’s distance from the wall it is following.
3. **PD controller for wall following** <br>
  The PD controller converts the side-wall distance error into a steering angle. The further the robot is from the target distance, the stronger it steers back toward the wall. The  derivative term helps reduce overshooting and oscillation.
4. **Fixed steering at corners.** <br>
  When a corner is detected because the front distance drops below a threshold, the robot temporarily stops using the side-wall PD controller and steers at a fixed angle until the path
  opens up again. This is more reliable for sharp corners than trying to follow the wall using PD control.
5. **Heading-based lap counting.** <br>
  Lap counting is handled independently from vision using the IMU’s heading. This makes lap counting more reliable even if the camera temporarily loses track of the wall.

#### 📉 System Workflow

```mermaid
flowchart TD
    A([START OPEN CHALLENGE]) --> B[Initialize System<br/>• RealSense D455<br/>• BNO055 IMU<br/>• Serial to ESP32<br/>• Flask HUD Server]

    B --> C[Zero IMU Heading<br/>Current direction = 0°<br/>lap_count = 0]

    C --> D[MAIN LOOP]

    D --> E[Capture and align depth and color frames<br/>640×480 @ 30 FPS]

    E --> F[Sample FRONT and SIDE ROIs from depth frame<br/>Median of valid pixels]

    F --> G[Read relative yaw from IMU<br/>Check checkpoint zone<br/>Update lap_count]

    G --> H{In a turn?}

    H -- YES --> I[TURN MODE<br/><br/>steer = fixed TURN_STEER<br/>speed = TURN_SPEED<br/><br/>Exit when front ≥ FRONT_CLEAR]

    H -- NO --> J[WALL-FOLLOW MODE<br/><br/>error = target − actual<br/>steer = Kp × error + Kd × derivative<br/>Clamp to STEER_LIMIT<br/>speed = BASE_SPEED<br/><br/>If side wall not seen:<br/>steer = SEARCH_STEER]

    I --> K[Send DRIVE command<br/>over serial to ESP32]
    J --> K

    K --> L{lap_count ≥ 3?}

    L -- NO --> D

    L -- YES --> M[Continue driving for<br/>STOP_DELAY_AFTER_LAPS]

    M --> N[Send DRIVE 0 0]
    N --> O([STOP])
```

### 🧱 Obstacle Avoidance
#### 📋 Challenge Requirements

The Obstacle Avoidance round requires the robot to complete 3 laps around the track while additionally detecting and correctly passing colored pillars placed along the path — green pillars must be passed on one side, red pillars on the other — without touching them or the track walls, and finally parking in a marked bay once the laps are complete.

As with the Open Challenge, the direction of travel is only revealed just before the run, so we again built two interchangeable driving programs, this time layering AI-based pillar detection and ultrasonic backup sensing on top of the same wall-following foundation:

| Mode | Wall Followed | Turn at Corners | Pillar Pass Direction |
|---|---|---|---|
| `obs_closewise.py` | Left wall | Turns **right** | Green → **left**, Red → **right** |
| `obs_counterclockwise.py` | Right wall | Turns **left** | Green → **left**, Red → **right** |

#### 🧭 Navigation Per File

**Left Wall Following + Obstacle Avoidance (`obs_clockwise.py`)**
- Follows the **left wall** using a PD controller.
- Makes a fixed **right turn** at corners and slows the turn as it gets close to the inner wall.
- Uses YOLO (`best1.pt`) to detect red and green pillars.
- Removes detected pillars from the depth data so they are not confused with the wall.
- Green pillars: steers left. Red pillars: steers right.
- Uses steering limits and ultrasonic sensors to prevent hitting the walls.
- Uses a corner-lock system so pillar avoidance has priority during turns.
- Stops and reverses briefly if a wall or pillar becomes dangerously close.
- Counts laps using the 90° → 180° → 270° → 0° checkpoints.

**Right Wall Following + Obstacle Avoidance (`obs_counterclockwise.py`)**
- Follows the right wall using a PD controller.
- Uses a fixed turning direction at corners for more reliable navigation.
- Uses YOLO (`best1.pt`) to detect and track pillars.
- Red pillars: steers left and follows the right wall.  
  Green pillars: steers right and follows the left wall.
- Adjusts steering based on the pillar's position and distance.
- Uses predictive steering to react before reaching a corner.
- Uses ultrasonic sensors as an additional safety system.
- Automatically calibrates the ultrasonic readings with the depth camera.
- Uses a corner-lock system to prioritize pillar avoidance during turns.
- Counts laps using IMU yaw instead of checkpoint zones.
  
#### 🎯 Our Strategy

1. **Depth camera for navigation and pillar ranging, YOLO for classification, IMU for lap counting.** <br>
   Steering during normal driving still relies entirely on the RealSense D455 depth stream, exactly as in the Open Challenge. YOLOv8 (`best1.pt`) is added purely to classify red vs. green pillars and locate them in the frame; the depth frame is then used to measure how far away each detected pillar actually is and to remove it from the wall-following ROIs.
2. **Column-based proportional avoidance instead of a fixed swing.** <br>
   Rather than steering a fixed amount whenever a pillar is seen, the controller computes an error between the pillar's current horizontal position and a target column, then steers proportionally — giving a smooth, continuously corrected pass rather than a single hard swerve.
3. **Independent wall-clearance guards as a safety net.** <br>
   Because wall-following, corner turns, and pillar avoidance can all issue a steering command in the same direction as a nearby wall, both directions of steering pass through dedicated inner-wall and outer-wall clearance guards before being sent to the motors — these only ever pull a dangerous steer back toward safe, never push it further into a wall.
4. **Ultrasonic sensors as a second, independent sensing layer.** <br>
   The RealSense depth ROIs and the ESP32's ultrasonic readings are treated as two independent measurements of the same wall; whichever one reports the more restrictive (closer) distance at any instant is the one that's obeyed, so a blind spot or dropout in one sensor doesn't remove the safety margin.
5. **Corner-lock and recovery for edge cases.** <br>
   A pillar appearing mid-turn cancels the turn and locks in pillar avoidance instead of fighting between the two behaviours every frame, and a stop-then-reverse recovery manoeuvre is triggered as a last resort if the front wall or a pillar gets dangerously close before the robot has fully cleared it.
6. **Heading-based lap counting, unchanged from the Open Challenge.** <br>
   Lap counting again runs independently of the vision pipeline using the IMU's heading, so it stays reliable even during active pillar avoidance, when the camera's attention is on the obstacle rather than the wall.

#### 📉 System Workflow

```mermaid
flowchart TD
    A([START OBSTACLE AVOIDANCE]) --> B[Initialize System<br/>• RealSense D455<br/>• BNO055 IMU<br/>• YOLOv8 model<br/>• Serial to ESP32<br/>• Flask HUD Server]

    B --> C[Zero IMU Heading<br/>Current direction = 0°<br/>lap_count = 0]

    C --> D[MAIN LOOP]

    D --> E[Capture and align depth and color frames<br/>640×480 @ 30 FPS]

    E --> F[Run YOLO on color frame<br/>Detect red/green pillars<br/>Mask boxes out of depth image]

    F --> G[Sample FRONT / LEFT / RIGHT ROIs<br/>from pillar-masked depth frame]

    G --> H[Read relative yaw from IMU<br/>Update lap_count]

    H --> I[Read left/right ultrasonic<br/>from ESP32]

    I --> J{Pillar within<br/>engage distance?}

    J -- YES --> K[PILLAR AVOID MODE<br/><br/>error = pillar cx − target column<br/>steer = Kp × error<br/>speed = AVOID_SPEED<br/><br/>Corner-lock cancels any active turn]

    J -- NO --> L{In a corner turn?}

    L -- YES --> M[TURN MODE<br/><br/>steer = fixed TURN_STEER<br/>speed = TURN_SPEED<br/><br/>Exit when front ≥ FRONT_CLEAR]

    L -- NO --> N[WALL-FOLLOW MODE<br/><br/>error = target − actual<br/>steer = Kp × error + Kd × derivative<br/>speed = BASE_SPEED]

    K --> O[Inner/Outer wall guards<br/>clamp steer using depth + ultrasonic]
    M --> O
    N --> O

    O --> P{Front wall or pillar<br/>critically close?}

    P -- YES --> Q[RECOVERY<br/>Stop, then reverse<br/>with small steer bias]
    P -- NO --> R[Send DRIVE command<br/>over serial to ESP32]
    Q --> R

    R --> S{lap_count ≥ 3?}

    S -- NO --> D

    S -- YES --> T[Continue driving for<br/>STOP_DELAY_AFTER_LAPS]

    T --> U[Send DRIVE 0 0]
    U --> V([STOP])
```

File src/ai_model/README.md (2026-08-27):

🤖 AI Model — Object Detection
====
This document describes the custom object detection model used by our robot to identify obstacles and the parking marker during the WRO 2026 Future Engineer Obstacle Avoidance round. It covers what the model detects, how it was trained, how it fits into the robot's control pipeline, and how to run it yourself.

## 📦 Overview

| | |
|---|---|
| **Framework** | [Ultralytics YOLOv8](https://docs.ultralytics.com/) |
| **Base architecture** | YOLOv8n (nano) |
| **Weights file** | `best1.pt` |
| **Input size** | 640 × 640 |
| **Classes** | 3 — `greenbox`, `redbox`, `xparking` |
| **Training epochs** | 100 |
| **Batch size** | 8 |
| **Optimizer** | Auto (Ultralytics auto-selects SGD/AdamW) |
| **Initial learning rate** | 0.01 |
| **Runs on** | NVIDIA Jetson (onboard, real time) |

We chose YOLOv8n specifically because it is the smallest/fastest variant in the YOLOv8 family, which matters a lot on Jetson-class hardware where the depth-processing wall-following loop already consumes a significant share of compute. Nano gives us real-time inference without needing to drop frame rate on the RealSense pipeline.

## 🎯 What the Model Detects

| Class ID | Label | Meaning | Robot Behavior |
|---|---|---|---|
| `0` | `greenbox` | Green obstacle pillar | Pass on the **right** side |
| `1` | `redbox` | Red obstacle pillar | Pass on the **left** side |
| `2` | `xparking` | Parking lot marker | Align and execute the parking maneuver |

The model only needs to distinguish these three classes, so we deliberately kept the dataset and label set narrow — this keeps training fast and inference accuracy very high, since the model isn't wasting capacity on classes it will never see on the competition field.

## 🏋️ Training Details

- **Dataset:** Custom-labeled images collected from our own track builds, captured at multiple distances, angles, and lighting conditions to make the model robust to venue lighting differences on competition day.
- **Labeling format:** YOLO format (`data.yaml` + per-image `.txt` label files), labeled with bounding boxes around each pillar/marker.
- **Augmentation:** Standard Ultralytics training-time augmentations (mosaic, HSV jitter, flips, scale/translate) were used to improve generalization from a relatively small custom dataset.
- **Hardware used for training:** trained on a CUDA GPU (`device=0`) using the Ultralytics training loop.

### 📊 Validation Performance

| Metric | Value |
|---|---|
| Precision | 0.997 |
| Recall | 0.985 |
| mAP@50 | 0.995 |
| mAP@50-95 | 0.928 |
| Box loss | 0.393 |
| Class loss | 0.172 |
| DFL loss | 0.791 |

These numbers come directly from the checkpoint's stored training metrics. The high precision/recall reflects the fact that the three target objects are visually distinct (solid red, solid green, and a printed "X" marker) and the dataset was collected under conditions close to the actual competition field.

## 🗂️ Files

```
ai_model/
└── best1.pt      # Trained YOLOv8n weights (best checkpoint by validation fitness)
```

`best1.pt` is a full Ultralytics checkpoint (not just raw weights) — it also stores the class names, training args, EMA weights, and training metrics, so it's self-describing and can be loaded directly without needing a separate `data.yaml` at inference time.

## ⚙️ Installation

The model requires the `ultralytics` package (which pulls in `torch` and `torchvision`):

```bash
pip install ultralytics
```

On the Jetson, install the Jetson-optimized PyTorch/TorchVision build first (per NVIDIA's Jetson PyTorch instructions for your JetPack version), then install `ultralytics` on top without letting it reinstall a non-Jetson torch build:

```bash
pip install ultralytics --no-deps
pip install opencv-python pyyaml pillow  # remaining ultralytics deps, torch/torchvision already installed
```

## ▶️ How to Use It

### 1. Quick test — run inference on an image or folder

```bash
yolo detect predict model=best1.pt source=path/to/image_or_folder conf=0.5
```

This saves annotated output images with bounding boxes under `runs/detect/predict/`.

### 2. Run inference from Python

```python
from ultralytics import YOLO

# Load the trained model
model = YOLO("best1.pt")

# Run inference on a single image
results = model("test_image.jpg", conf=0.5)

# Inspect detections
for r in results:
    for box in r.boxes:
        cls_id = int(box.cls[0])
        label = model.names[cls_id]       # 'greenbox' / 'redbox' / 'xparking'
        confidence = float(box.conf[0])
        x1, y1, x2, y2 = box.xyxy[0].tolist()
        print(f"{label} ({confidence:.2f}) at [{x1:.0f}, {y1:.0f}, {x2:.0f}, {y2:.0f}]")
```

### 3. Live inference on the robot (RealSense color stream)

This is how the model is actually used on the robot during the Obstacle Avoidance round — run continuously on each incoming color frame, with detections then fused against the aligned depth frame to get real-world distance/offset:

```python
import pyrealsense2 as rs
import numpy as np
from ultralytics import YOLO

model = YOLO("best1.pt")

pipeline = rs.pipeline()
config = rs.config()
config.enable_stream(rs.stream.color, 640, 480, rs.format.bgr8, 30)
config.enable_stream(rs.stream.depth, 640, 480, rs.format.z16, 30)
pipeline.start(config)
align = rs.align(rs.stream.color)

while True:
    frames = pipeline.wait_for_frames()
    frames = align.process(frames)
    color_frame = frames.get_color_frame()
    depth_frame = frames.get_depth_frame()
    if not color_frame or not depth_frame:
        continue

    color_image = np.asanyarray(color_frame.get_data())
    results = model(color_image, conf=0.5, verbose=False)

    for r in results[0].boxes:
        cls_id = int(r.cls[0])
        label = model.names[cls_id]
        x1, y1, x2, y2 = map(int, r.xyxy[0])
        cx, cy = (x1 + x2) // 2, (y1 + y2) // 2   # box center pixel

        # Look up real-world distance at the box center from the depth frame
        distance_m = depth_frame.get_distance(cx, cy)

        print(f"{label} at {distance_m:.2f}m, pixel center ({cx},{cy})")
        # -> feed (label, distance_m, cx) into the steering/decision logic
```

### 4. Useful inference parameters

| Parameter | Purpose | Typical value on our robot |
|---|---|---|
| `conf` | Minimum confidence to keep a detection | `0.5` |
| `iou` | NMS IoU threshold for overlapping boxes | `0.45` (default) |
| `imgsz` | Inference resolution | `640` (matches training size) |
| `device` | Run on GPU (`0`) or CPU (`'cpu'`) | `0` (Jetson GPU) |
| `half` | FP16 inference for speed | `True` on Jetson |

Example with FP16 for faster Jetson inference:

```python
results = model(color_image, conf=0.5, imgsz=640, device=0, half=True, verbose=False)
```

## 🔗 How It Fits Into the Robot's Pipeline

1. **Color frame in →** YOLOv8n runs inference on each RealSense color frame, returning class, confidence, and bounding box for every detected `greenbox`, `redbox`, or `xparking` instance.
2. **Depth fusion →** the pixel center of each box is looked up in the depth frame to get a real-world distance and lateral offset, turning a 2D detection into an actionable 3D position.
3. **Decision logic →** the robot computes a steering correction so it passes green pillars on the right and red pillars on the left, layered on top of the existing wall-following PD controller.
4. **Parking →** once the lap requirement is met, `xparking` detections are used to center and align the robot with the parking bay before triggering the parking sequence.
5. **Redundancy →** ultrasonic sensors back up the vision pipeline at close range in case a frame is missed or a detection comes in late.

YOLO inference is only enabled during the Obstacle Avoidance round — it's switched off entirely for the Open Challenge, since there are no pillars to detect and disabling it frees up Jetson compute for the depth-based navigation loop.

## ⚠️ Limitations & Notes

- The model was trained on our own track builds; if lighting or pillar material at the competition differs significantly from our test conditions, confidence may drop and `conf` may need re-tuning on the day.
- `xparking` detection assumes the marker is unobstructed and roughly frontal — steep viewing angles reduce detection reliability, which is why the robot only starts looking for it once it's already aligned along the expected approach path.
- The model does not track objects across frames (no built-in tracker); temporal smoothing/debouncing of detections is handled in the decision logic layer, not inside the model itself.

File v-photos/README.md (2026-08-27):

Vehicle's photos
====
This folder contains a complete photo gallery of our robot, capturing it from different angles and highlighting its design, structure, and build quality. From the overall appearance to the smaller details, these photos give you a closer look at how our robot is built and how all its components come together.

| Top photo | Bottom photo |
| :---: | :---: |
| **Top** | **Bottom** |

| Left photo | Right photo |
| :---: | :---: |
| **Left** | **Right** |

| Front photo | Back photo |
| :---: | :---: |
| **Front** | **Back** |

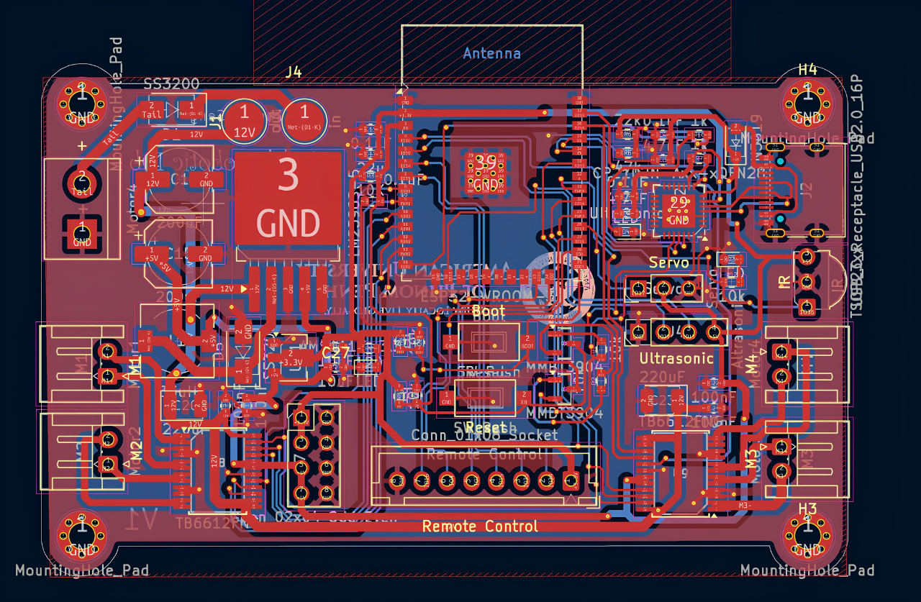
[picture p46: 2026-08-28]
schemes/photos/PCB_Routing.png

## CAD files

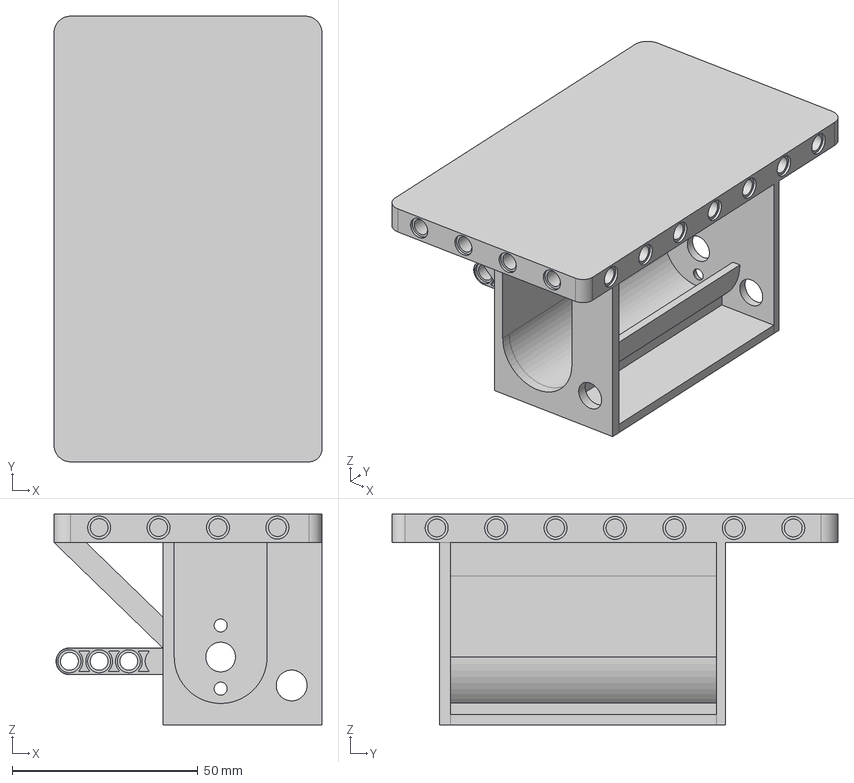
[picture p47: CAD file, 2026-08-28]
models/STEP_file/MotorMountV4.step
72.2 x 120.0 x 56.7 mm

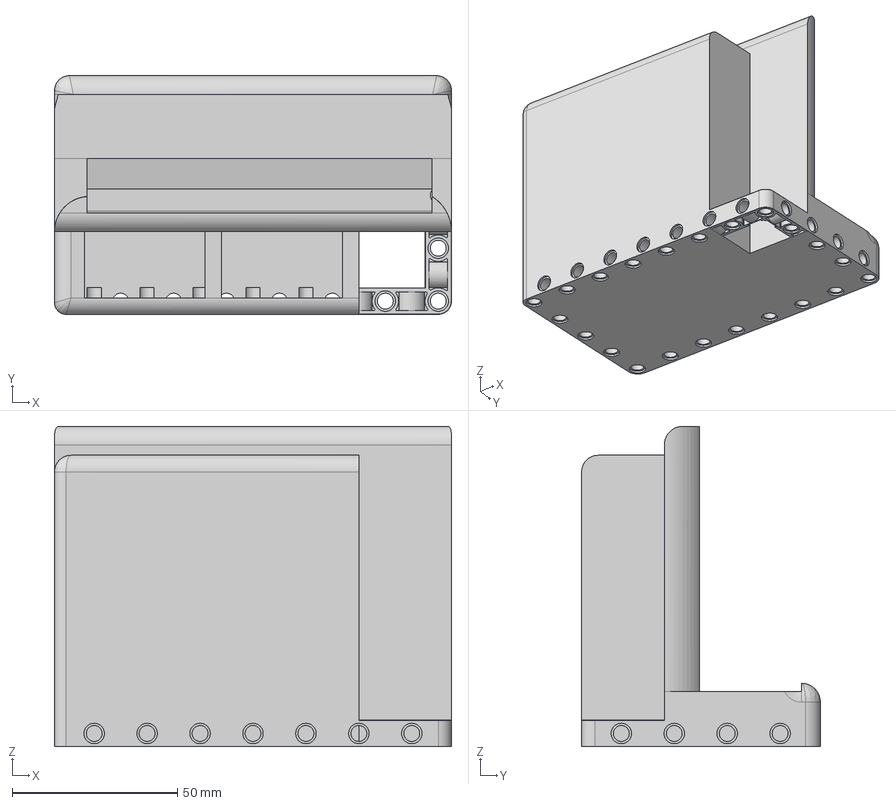
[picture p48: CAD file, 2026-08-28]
models/STEP_file/JetsonAndBatteryV3.step
120.0 x 72.2 x 96.9 mm

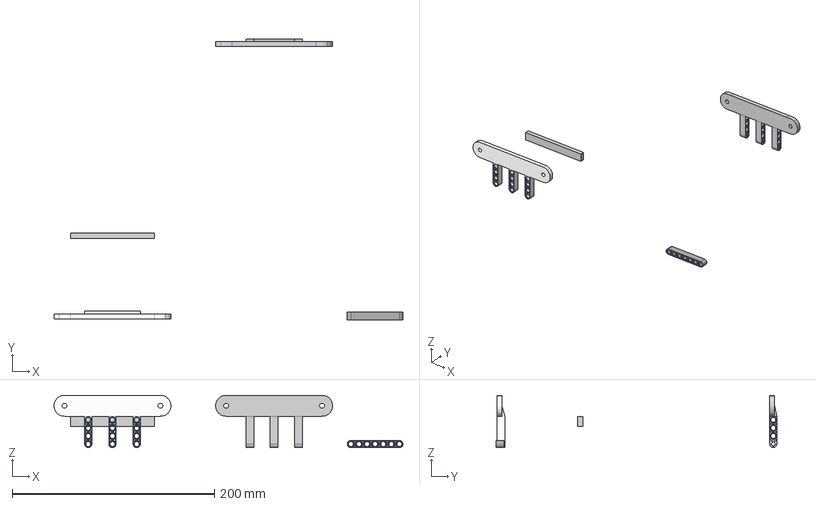
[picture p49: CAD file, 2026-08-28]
models/STEP_file/RealSenseV2.step
345.5 x 278.0 x 51.9 mm
D455 Main Mount v1
5m Beam 4210686/32316
7M Beam 4495931/32524
AngleBeam v2
D455 Main Mount v1 (1)

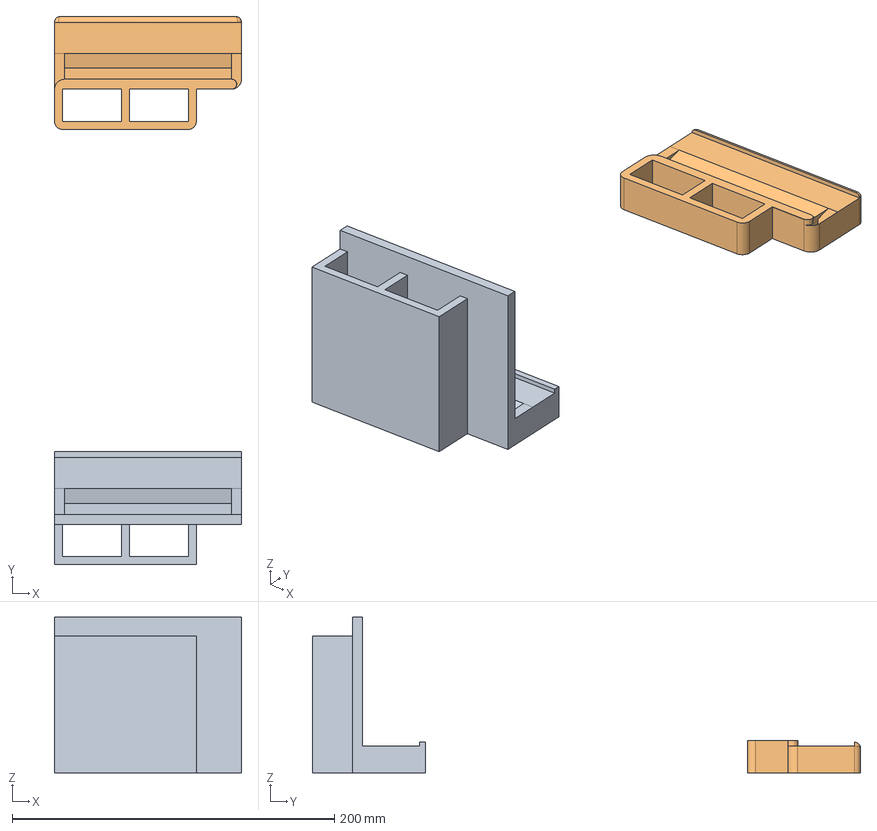
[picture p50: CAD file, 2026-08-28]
models/STEP_file/JetsonAndBatteryP1.step
116.0 x 340.2 x 96.8 mm

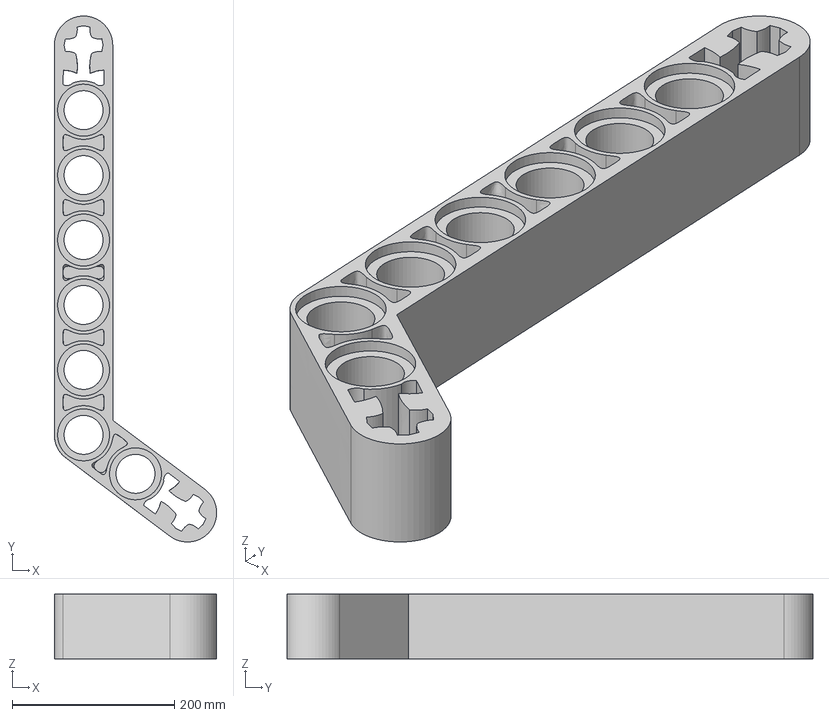
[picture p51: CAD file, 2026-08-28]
models/STEP_file/LegoAngleBeam.step
200.0 x 648.0 x 80.0 mm

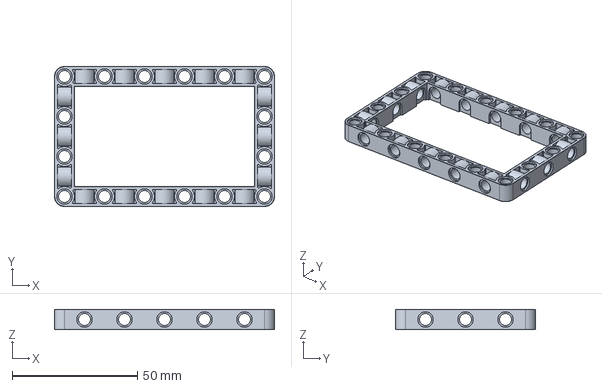
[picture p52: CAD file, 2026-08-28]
models/STEP_file/LegoBeamFrame.step
88.0 x 56.0 x 8.00 mm

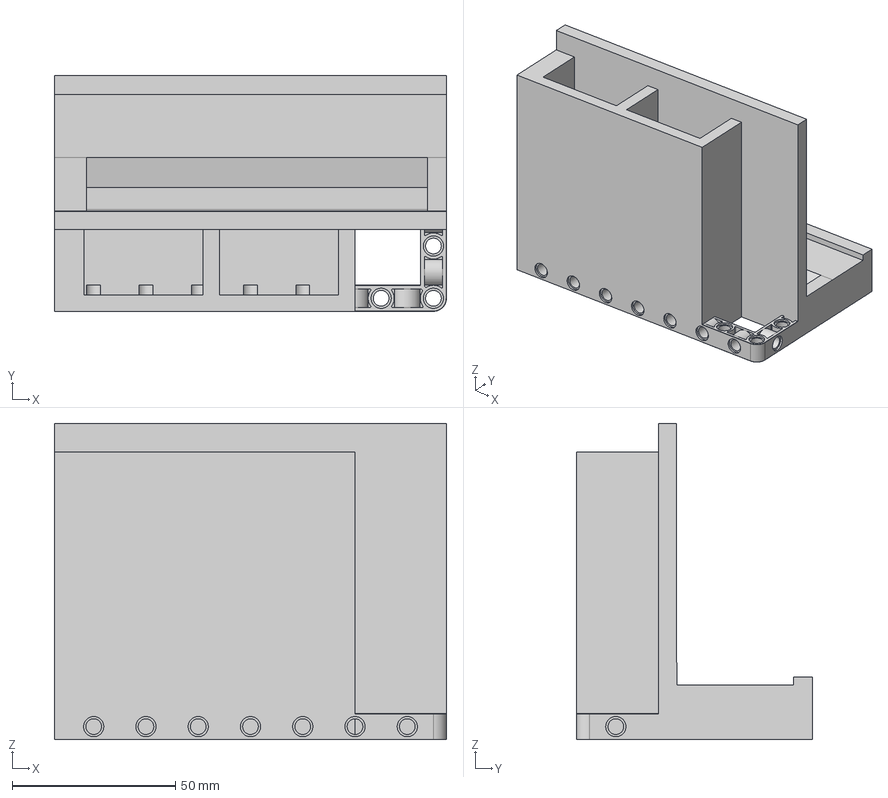
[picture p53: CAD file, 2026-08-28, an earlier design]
models/STEP_file/JetsonAndBatteryV2.step
120.0 x 72.2 x 96.9 mm

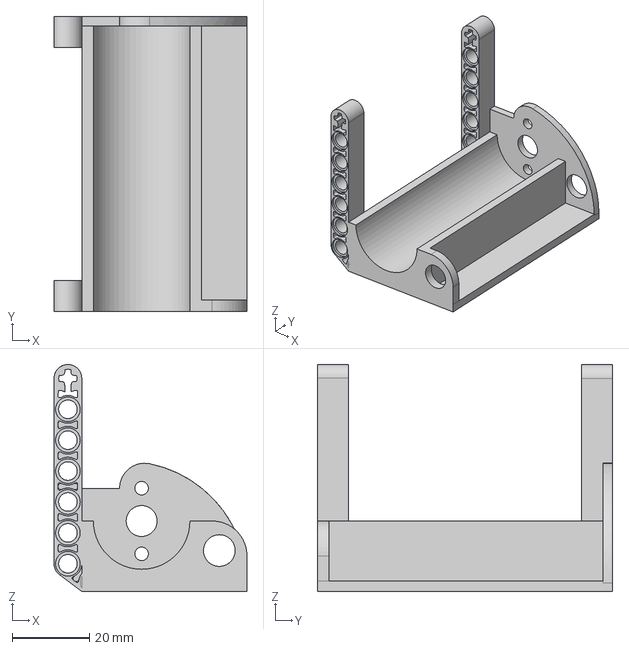
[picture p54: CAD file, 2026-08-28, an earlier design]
models/STEP_file/MotorMountV2.step
50.0 x 76.5 x 58.8 mm

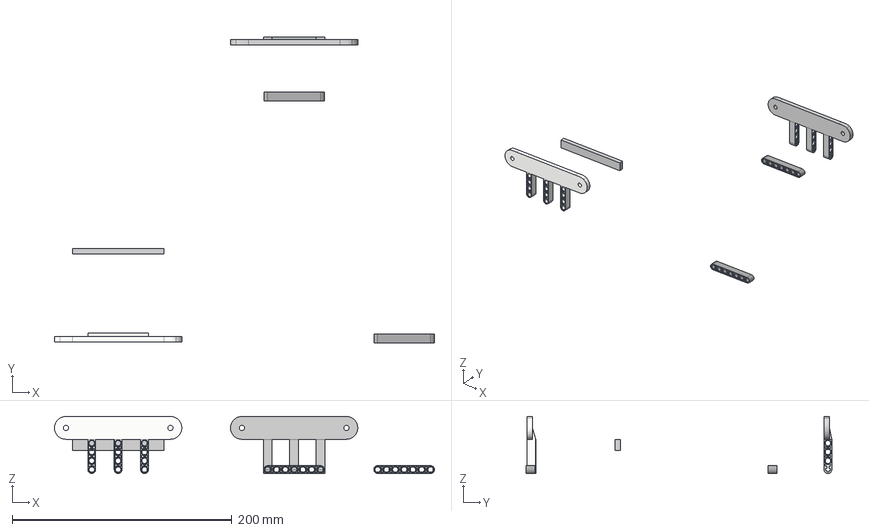
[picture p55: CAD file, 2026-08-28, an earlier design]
models/STEP_file/RealSenseV1.step
345.5 x 278.0 x 51.9 mm
D455 Main Mount v1
5m Beam 4210686/32316
7M Beam 4495931/32524 x 2
AngleBeam v2
D455 Main Mount v1 (1)

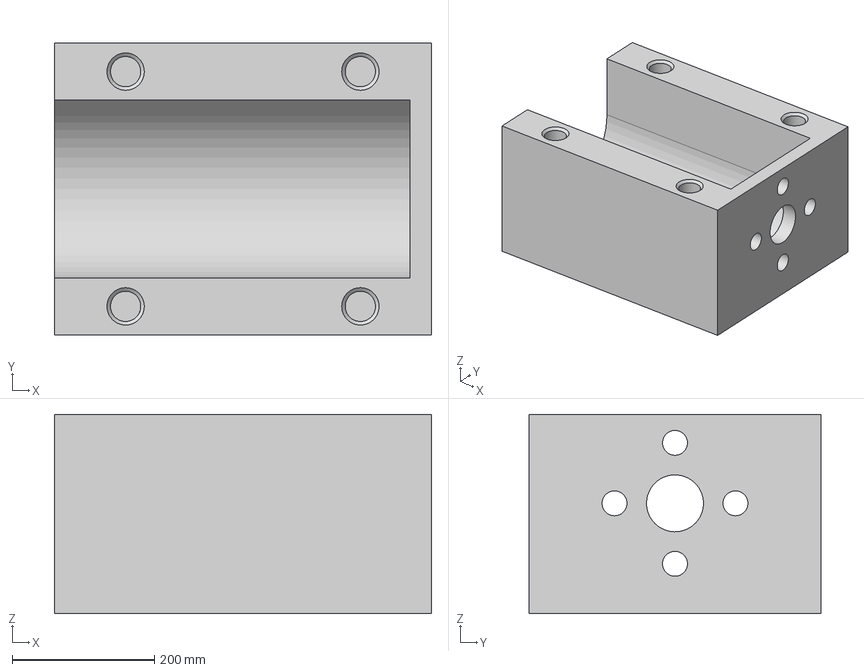
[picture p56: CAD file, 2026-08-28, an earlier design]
models/STEP_file/MotorMountV1.step
530.0 x 410.0 x 280.0 mm

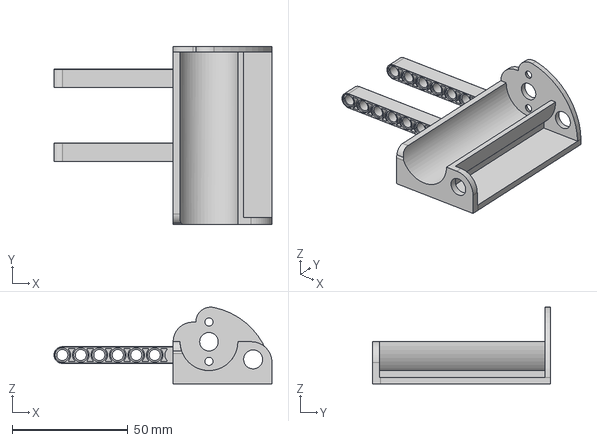
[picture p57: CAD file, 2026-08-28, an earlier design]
models/STEP_file/MotorMountV3.step
94.4 x 77.0 x 33.2 mm
AngleBeam v2
7M Beam 4495931/32524

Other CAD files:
models/STEP_file/JetsonAndBatteryV1.step
models/STL_file/JetsonAndBatteryP1.stl
models/STL_file/JetsonAndBatteryV1.stl
models/STL_file/JetsonAndBatteryV2.stl
models/STL_file/JetsonAndBatteryV3.stl
models/STL_file/LegoAngleBeam.stl
models/STL_file/LegoBeamFrame.stl
models/STL_file/MotorMountV1.stl
models/STL_file/MotorMountV2.stl
models/STL_file/MotorMountV3.stl
models/STL_file/MotorMountV4.stl
models/STL_file/RealSenseV1.stl
models/STL_file/RealSenseV2.stl

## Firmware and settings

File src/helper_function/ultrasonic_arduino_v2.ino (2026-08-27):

#include <ESP32Servo.h>

// ══════════════════════════════════════════════════════════════════════════════
//  ULTRASONIC PINS
//  Hardware: LEFT ultrasonic + RIGHT ultrasonic
//  Serial output:
//      USL <cm>
//      USR <cm>
// ══════════════════════════════════════════════════════════════════════════════

// LEFT ultrasonic
#define LEFT_TRIG_PIN  13
#define LEFT_ECHO_PIN  39

// RIGHT ultrasonic
#define RIGHT_TRIG_PIN 4
#define RIGHT_ECHO_PIN 16

// Send ultrasonic data every 100 ms
unsigned long lastUltrasonicTime = 0;
const unsigned long ULTRASONIC_INTERVAL = 100;

// ══════════════════════════════════════════════════════════════════════════════
//  MOTOR / SERVO PINS
// ══════════════════════════════════════════════════════════════════════════════
#define SERVO_PIN     17
#define MOTOR_IN1     26
#define MOTOR_IN2     25
#define MOTOR_PWM_PIN 33
#define MOTOR_PWM_CH  2
#define MOTOR_FREQ    20000
#define MOTOR_RES     8

// ══════════════════════════════════════════════════════════════════════════════
//  SERVO SETTINGS
//  right = +, left = -
// ══════════════════════════════════════════════════════════════════════════════
const int SERVO_MIN = 35;
const int SERVO_MAX = 145;
const int SERVO_MID = 90;

const int TURN_AMT    = 35;
const int CORRECT_AMT = 25;
const int NUDGE_AMT   = 4;

// ══════════════════════════════════════════════════════════════════════════════
//  MOTOR SETTINGS
// ══════════════════════════════════════════════════════════════════════════════
const int MOTOR_SPEED = 120;

// ══════════════════════════════════════════════════════════════════════════════
Servo myServo;
int servoAngle = SERVO_MID;

// Serial command buffer
char buf[40];
uint8_t idx = 0;

// ══════════════════════════════════════════════════════════════════════════════
//  MOTOR / SERVO HELPERS
// ══════════════════════════════════════════════════════════════════════════════
void motorForward() {
  digitalWrite(MOTOR_IN1, HIGH);
  digitalWrite(MOTOR_IN2, LOW);
  ledcWrite(MOTOR_PWM_CH, MOTOR_SPEED);
}

void motorBackward() {
  digitalWrite(MOTOR_IN1, LOW);
  digitalWrite(MOTOR_IN2, HIGH);
  ledcWrite(MOTOR_PWM_CH, MOTOR_SPEED);
}

void motorStop() {
  digitalWrite(MOTOR_IN1, LOW);
  digitalWrite(MOTOR_IN2, LOW);
  ledcWrite(MOTOR_PWM_CH, 0);
}

void motorDriveForward(int speed) {
  speed = constrain(speed, 0, 255);

  if (speed == 0) {
    motorStop();
    return;
  }

  digitalWrite(MOTOR_IN1, HIGH);
  digitalWrite(MOTOR_IN2, LOW);
  ledcWrite(MOTOR_PWM_CH, speed);
}

void motorDriveBackward(int speed) {
  speed = constrain(speed, 0, 255);

  if (speed == 0) {
    motorStop();
    return;
  }

  digitalWrite(MOTOR_IN1, LOW);
  digitalWrite(MOTOR_IN2, HIGH);
  ledcWrite(MOTOR_PWM_CH, speed);
}

void setServo(int angle) {
  servoAngle = constrain(angle, SERVO_MIN, SERVO_MAX);
  myServo.write(servoAngle);
}

// ══════════════════════════════════════════════════════════════════════════════
//  ULTRASONIC FUNCTIONS
// ══════════════════════════════════════════════════════════════════════════════
float readUltrasonicCm(int trigPin, int echoPin) {
  digitalWrite(trigPin, LOW);
  delayMicroseconds(2);

  digitalWrite(trigPin, HIGH);
  delayMicroseconds(10);
  digitalWrite(trigPin, LOW);

  long duration = pulseIn(echoPin, HIGH, 25000);  // 25 ms timeout

  if (duration == 0) {
    return -1.0;   // no echo
  }

  float distance = (duration * 0.0343) / 2.0;
  return distance;
}

void sendUltrasonicData() {
  float leftCm = readUltrasonicCm(LEFT_TRIG_PIN, LEFT_ECHO_PIN);
  delay(5);  // small delay to reduce ultrasonic interference

  float rightCm = readUltrasonicCm(RIGHT_TRIG_PIN, RIGHT_ECHO_PIN);

  // LEFT ultrasonic data
  if (leftCm < 0) {
    Serial.println("USL NO_ECHO");
  } else {
    Serial.print("USL ");
    Serial.println(leftCm, 2);
  }

  // RIGHT ultrasonic data
  if (rightCm < 0) {
    Serial.println("USR NO_ECHO");
  } else {
    Serial.print("USR ");
    Serial.println(rightCm, 2);
  }
}

// ══════════════════════════════════════════════════════════════════════════════
//  COMMAND HANDLER
// ══════════════════════════════════════════════════════════════════════════════
void handleCommand(char* cmd) {
  // Forward proportional drive:
  // DRIVE <steerDeg> <speed>
  // Example: DRIVE -20 110
  if (strncmp(cmd, "DRIVE ", 6) == 0) {
    int steer = 0;
    int spd = 0;

    if (sscanf(cmd + 6, "%d %d", &steer, &spd) == 2) {
      setServo(SERVO_MID + steer);
      motorDriveForward(spd);

      Serial.print("OK DRIVE s=");
      Serial.print(servoAngle);
      Serial.print(" v=");
      Serial.println(spd);
    } else {
      Serial.println("BAD DRIVE");
    }

    return;
  }

  // Backward proportional drive:
  // BACK <steerDeg> <speed>
  // Example: BACK 15 90
  if (strncmp(cmd, "BACK ", 5) == 0) {
    int steer = 0;
    int spd = 0;

    if (sscanf(cmd + 5, "%d %d", &steer, &spd) == 2) {
      setServo(SERVO_MID + steer);
      motorDriveBackward(spd);

      Serial.print("OK BACK s=");
      Serial.print(servoAngle);
      Serial.print(" v=");
      Serial.println(spd);
    } else {
      Serial.println("BAD BACK");
    }

    return;
  }

  // Discrete commands
  if      (strcmp(cmd, "FORWARD")       == 0) { setServo(SERVO_MID);               motorForward();  }
  else if (strcmp(cmd, "BACKWARD")      == 0) { setServo(SERVO_MID);               motorBackward(); }
  else if (strcmp(cmd, "STOP")          == 0) { setServo(SERVO_MID);               motorStop();     }

  else if (strcmp(cmd, "TURN_RIGHT")    == 0) { setServo(SERVO_MID + TURN_AMT);    motorForward();  }
  else if (strcmp(cmd, "TURN_LEFT")     == 0) { setServo(SERVO_MID - TURN_AMT);    motorForward();  }

  else if (strcmp(cmd, "BACK_RIGHT")    == 0) { setServo(SERVO_MID + TURN_AMT);    motorBackward(); }
  else if (strcmp(cmd, "BACK_LEFT")     == 0) { setServo(SERVO_MID - TURN_AMT);    motorBackward(); }

  else if (strcmp(cmd, "CORRECT_RIGHT") == 0) { setServo(SERVO_MID + CORRECT_AMT); motorForward();  }
  else if (strcmp(cmd, "CORRECT_LEFT")  == 0) { setServo(SERVO_MID - CORRECT_AMT); motorForward();  }

  else if (strcmp(cmd, "NUDGE_RIGHT")   == 0) { setServo(SERVO_MID + NUDGE_AMT);   motorForward();  }
  else if (strcmp(cmd, "NUDGE_LEFT")    == 0) { setServo(SERVO_MID - NUDGE_AMT);   motorForward();  }

  else {
    Serial.print("Unknown cmd: ");
    Serial.println(cmd);
    return;
  }

  Serial.print("OK ");
  Serial.print(cmd);
  Serial.print(" servo=");
  Serial.println(servoAngle);
}

// ══════════════════════════════════════════════════════════════════════════════
//  SETUP
// ══════════════════════════════════════════════════════════════════════════════
void setup() {
  Serial.begin(115200);

  // Ultrasonic sensors
  pinMode(LEFT_TRIG_PIN, OUTPUT);
  pinMode(LEFT_ECHO_PIN, INPUT);
  digitalWrite(LEFT_TRIG_PIN, LOW);

  pinMode(RIGHT_TRIG_PIN, OUTPUT);
  pinMode(RIGHT_ECHO_PIN, INPUT);
  digitalWrite(RIGHT_TRIG_PIN, LOW);

  // Servo
  ESP32PWM::allocateTimer(0);
  myServo.setPeriodHertz(50);
  myServo.attach(SERVO_PIN);
  myServo.write(SERVO_MID);

  // Motor
  pinMode(MOTOR_IN1, OUTPUT);
  pinMode(MOTOR_IN2, OUTPUT);

  ledcSetup(MOTOR_PWM_CH, MOTOR_FREQ, MOTOR_RES);
  ledcAttachPin(MOTOR_PWM_PIN, MOTOR_PWM_CH);

  motorStop();

  Serial.println("ESP32 ready");
}

// ══════════════════════════════════════════════════════════════════════════════
//  LOOP
// ══════════════════════════════════════════════════════════════════════════════
void loop() {
  // 1. Read Jetson commands
  while (Serial.available()) {
    char c = Serial.read();

    if (c == '\n' || c == '\r') {
      if (idx > 0) {
        buf[idx] = '\0';
        handleCommand(buf);
        idx = 0;
      }
    } else if (idx < sizeof(buf) - 1) {
      buf[idx++] = c;
    }
  }

  // 2. Send ultrasonic data every 100 ms
  unsigned long now = millis();

  if (now - lastUltrasonicTime >= ULTRASONIC_INTERVAL) {
    lastUltrasonicTime = now;
    sendUltrasonicData();
  }
}

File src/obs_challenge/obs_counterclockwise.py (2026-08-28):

#!/usr/bin/env python3
import cv2
import time
import signal
import threading
import re
import json
import os
import numpy as np
import serial
import pyrealsense2 as rs
from flask import Flask, Response
from ultralytics import YOLO
from bno055_yaw import BNO055Yaw


# ══════════════════════════════════════════════════════════════════════════
#  TUNABLES
# ══════════════════════════════════════════════════════════════════════════
SERIAL_PORT = "/dev/esp32"
SERIAL_BAUD = 115200


class ResilientSerial:
  def __init__(self, port=SERIAL_PORT, baud=SERIAL_BAUD):
      self.port = port
      self.baud = baud
      self.ser = None
      self.lock = threading.Lock()
      self._connect()




  def _connect(self):
      while True:
          try:
              if self.ser:
                  try:
                      self.ser.close()
                  except Exception:
                      pass
              self.ser = serial.Serial(self.port, self.baud, timeout=1)
              print(f"[SERIAL] connected to {self.port}")
              return
          except (serial.SerialException, FileNotFoundError) as e:
              print(f"[SERIAL] connect failed: {e}, retrying in 1s")
              time.sleep(1)




  def write(self, data):
      with self.lock:
          try:
              self.ser.write(data)
              return True
          except (serial.SerialException, OSError) as e:
              print(f"[SERIAL] write failed: {e}, reconnecting")
              self._connect()
              return False




  def read(self, size=1):
      with self.lock:
          try:
              return self.ser.read(size)
          except (serial.SerialException, OSError) as e:
              print(f"[SERIAL] read failed: {e}, reconnecting")
              self._connect()
              return b""




  def readline(self):
      with self.lock:
          try:
              return self.ser.readline()
          except (serial.SerialException, OSError) as e:
              print(f"[SERIAL] readline failed: {e}, reconnecting")
              self._connect()
              return b""


SERIAL_TIMEOUT = 0.05


# ---- wall following ---------------------------------------------------
RIGHT_TARGET  = 0.90    # m — desired distance to right wall
FRONT_STOP    = 0.8     # m — front wall closer than this -> forced turn
FRONT_CLEAR   = 0.55    # m — front must open past this to leave turn mode
KP_STEER      = 45.0    # deg per m of right-wall error
KD_STEER      = 3.0     # FIX v2.11-b: lowered 6 -> 3, derr itself smoothed
STEER_LIMIT   = 30       # max |steer| deg
BASE_SPEED    = 150      # PWM during normal wall following
TURN_SPEED    = 160      # PWM during the forced turn
TURN_STEER_MAG = 35      # magnitude of hard turn steer; sign picked dynamically




# FIX (v2.24): right-wall follower must ALWAYS corner the same physical
# direction (toward/around the wall it is hugging) instead of "deciding"
# per corner which side looks more open. Comparing l_room/r_room (as the
# old code did) is a "head toward open space" strategy and can pick the
# wrong direction whenever the depth camera misreads an open doorway,
# a reflective surface, a missing wall segment, etc. A pure right-wall
# follower doesn't need that decision at all -- it always turns the same
# way at a blocked front, exactly like the working depth-only reference
# script. Set this to match your track's corner direction.
TURN_DIRECTION = -1   # -1 = turn LEFT at a blocked front, +1 = turn RIGHT




# FIX (v2.11-a): deadband on FOLLOW-mode wall-follow error. Error smaller
# than this (in meters) is treated as exactly 0 before P/D math, so small
# sensor noise around RIGHT_TARGET doesn't flip steer sign every frame.
FOLLOW_ERR_DEADBAND = 0.05   # m




# FIX (v2.11-b): light smoothing on the derivative term itself, separate
# from the EMA already applied to right_d. Keeps a single noisy frame from
# injecting a derivative spike into steer.
DERR_ALPHA = 0.5




# ---- minimum moving speed / startup kick --------------------------
MIN_MOVE_SPEED   = 130
STARTUP_KICK_PWM = 220
STARTUP_KICK_MS  = 150


# ---- predictive front avoidance -----------------------------------
FRONT_WARN          = 0.9
FRONT_RATE_GAIN     = 25.0
FRONT_BIAS_MAX_FRAC = 0.4




# ---- steering smoothing -------------------------------------------
# FIX (v2.11-c): split the single MAX_STEER_DELTA into a gentler
# "normal driving" limit and a faster "urgent/wall-push/turn" limit.
MAX_STEER_DELTA_FOLLOW = 18.0
MAX_STEER_DELTA_URGENT = 24.0


# FIX (v2.12-c): ultrasonic hard-safety clamp gets its OWN, much faster
# slew limit. This is your last line of defense against a physical hit
# and it was previously throttled by the same cap as normal driving.
MAX_STEER_DELTA_US_HARD = 34.0   # close to STEER_LIMIT — near-instant




# FIX (v2.11-e): one more light EMA on the final commanded steer, applied
# after the slew-rate limiter, right before sending to the ESP32.
# FIX (v2.12-b): this smoothing is now SKIPPED entirely whenever
# urgent_now is true (turn / wall clamp / us clamp), since smoothing an
# already-slew-limited emergency correction just adds more lag on top of
# lag. It still applies during normal FOLLOW driving.
STEER_OUT_ALPHA = 0.6   # weight on the new value; 1.0 = no smoothing




# ---- right-wall / left-wall dropout recovery -----------------------------
# FIX (v2.12-a): shortened from 0.5s. At BASE_SPEED the old timeout let the
# robot hold a stale (too-generous) distance for a long time after the
# sensor stopped returning valid data — exactly when the wall was getting
# dangerously close and roi_distance started starving for valid pixels.
RIGHT_HOLD_TIMEOUT = 0.25  # s — how long to trust the last-known distance




UNKNOWN_RIGHT_ROOM_M = 0.30   # m — assume close/unsafe, NOT open
UNKNOWN_LEFT_ROOM_M  = 1.00   # m — neutral, matches turn_dir fallback
US_CONFIRM_CLOSE_CM  = 15.0   # cm — if ultrasonic agrees right is close, trust it directly


# ---- corner detection (front-left / front-right diagonal) ----------
FRONT_LEFT_ROI  = (0.30, 0.42, 0.40, 0.60)
FRONT_RIGHT_ROI = (0.60, 0.80, 0.35, 0.65)


# ---- EMA depth smoothing -------------------------------------------
ALPHA_DEPTH = 0.4


# ---- ultrasonic side-wall safety (independent of depth camera) ------------
US_ENABLED         = True
US_LEFT_AVOID_CM   = 25.0
US_RIGHT_AVOID_CM  = 20.0
US_STALE_TIMEOUT   = 0.5


US_MOUNT_OFFSET_CM = 0.0


US_AUTOCALIB_ENABLED   = True
US_CALIB_ALPHA         = 0.01
US_CALIB_TRUST_MIN_M   = 0.20
US_CALIB_TRUST_MAX_M   = 1.20
US_CALIB_MAX_OFFSET_CM = 40.0
US_CALIB_FILE          = os.path.join(os.path.dirname(os.path.abspath(__file__)),
                                     "us_calib.json")
US_CALIB_SAVE_EVERY_S  = 5.0




# ---- pillar detection / avoidance -----------------------------------------
MODEL_PATH    = "best1.pt"
CONF_THRES    = 0.35
IMG_SIZE      = 416
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

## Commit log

2026-08-26 added electrical wiring diagram
2026-08-26 Add system workflow flowchart to README
    Added a flowchart to illustrate the system workflow and algorithms.
2026-08-27 add steering visual
2026-08-27 add back wheel model
2026-08-27 add esp32 code
2026-08-27 Fix case sensitivity in ClockWise.py command
2026-08-28 add imu pic
2026-08-28 Rename PCB Routing.png to PCB_Routing.png
2026-08-28 Rename PCB Schematics.png to PCB_Schematics.png
2026-08-28 engineering journal
    [JetsonAndBatteryP1.step, JetsonAndBatteryP1.stl, JetsonAndBatteryV1.step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]
2026-08-28 add pic
    Updated the wiring block diagram image in the README.
2026-08-28 Update power domain table with detailed specifications
2026-08-28 Remove torque and speed summary section
    Removed the torque and speed summary section from the README.
2026-08-28 Remove TODO section for torque and speed summary
    Removed TODO section for torque and speed summary from README.
2026-08-28 Enhance README with setup and assembly instructions
    Updated the README to include detailed hardware and software requirements, mechanical assembly instructions, wiring guidelines, and power-on procedures.
2026-08-28 Update Print Settings status to finalized
2026-08-28 Remove gear ratio confirmation note from README
    Removed note about confirming motor gear ratio from README.
